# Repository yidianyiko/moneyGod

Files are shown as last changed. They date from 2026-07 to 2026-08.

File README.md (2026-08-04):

# 赛博财神庙 (MoneyGod)

AdventureX 2026 黑客松项目 — 一台桌面"财神"装置：摇签 → 抽档 → LLM 生成签诗 + 解签 → TTS 语音播报 → 热敏打印签条。

核心硬件基于 Tuya T5AI 开发板 + 热敏打印机 + 磁悬浮展示 + 摇签遥控器，外壳为 3D 打印件。后端 Python 服务提供签文生成、TTS 合成等 API。

> 详细架构与开发指南见 [`CLAUDE.md`](CLAUDE.md)。

## 成品展示

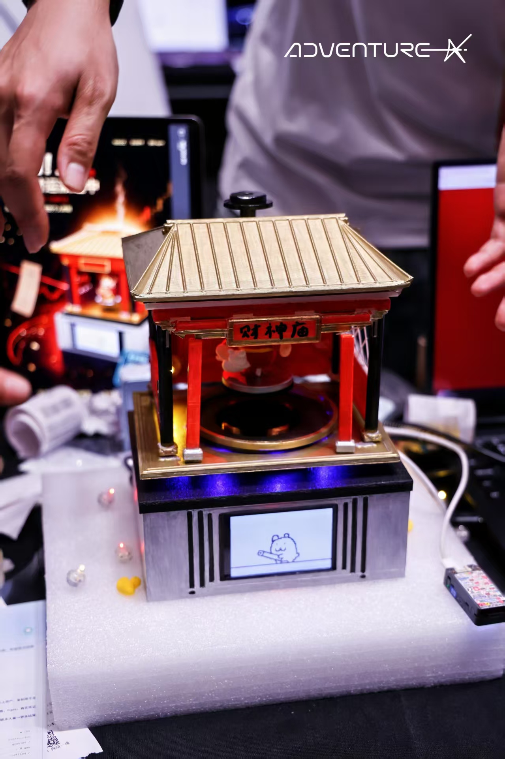
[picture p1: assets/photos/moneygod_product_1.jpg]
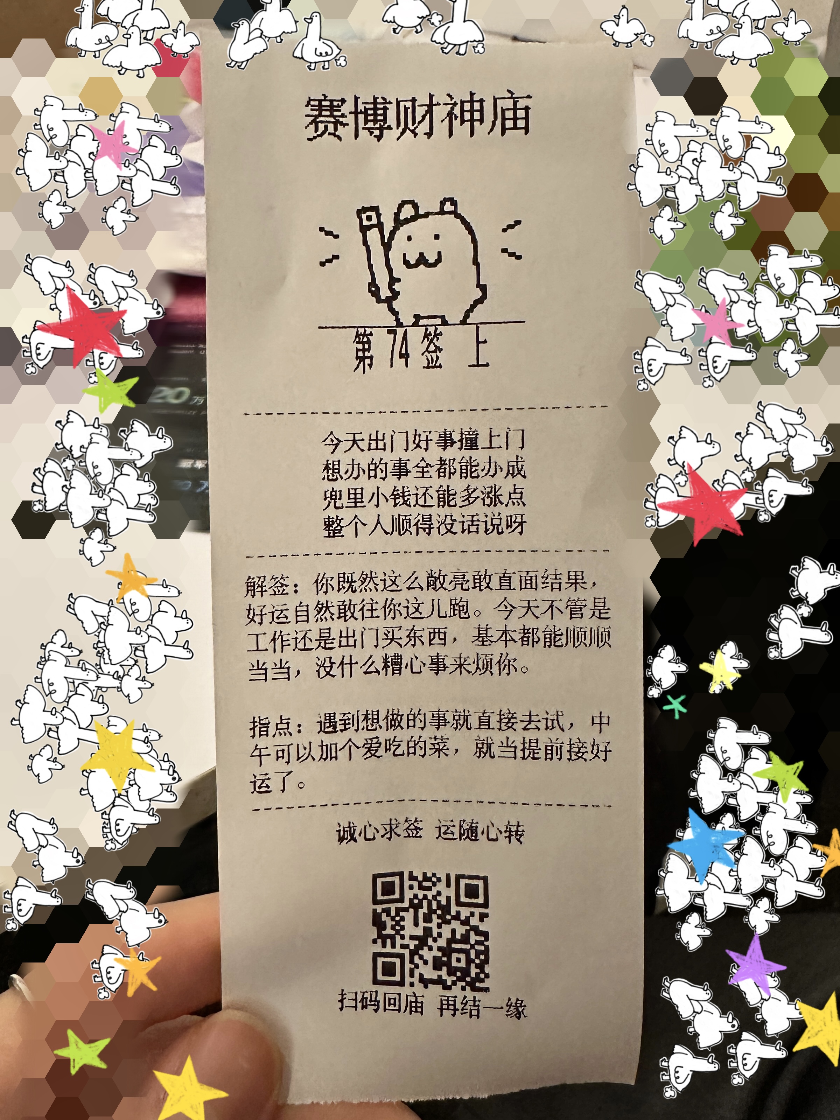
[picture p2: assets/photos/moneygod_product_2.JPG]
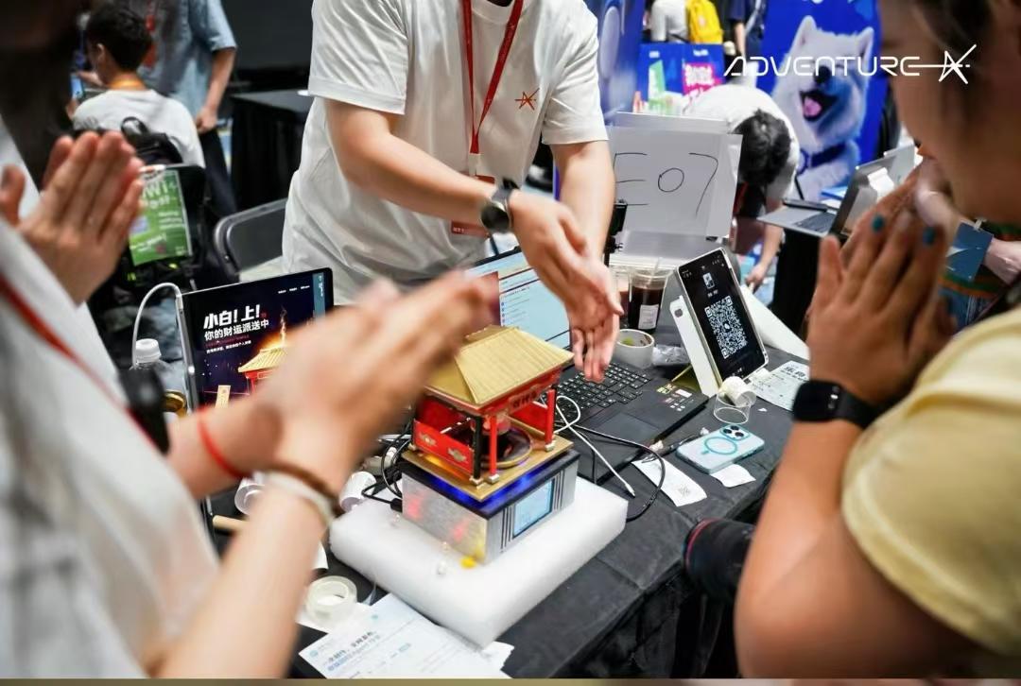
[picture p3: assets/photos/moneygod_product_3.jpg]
<table> <tr> <td align="center" valign="top" width="50%">  </td> <td align="center" valign="top" width="50%">  </td> </tr> </table>   

---

## 硬件清单 (BOM)

> 📝 搜索建议：可直接在淘宝/电商平台搜索以下商品名称。

> 💰 完整成本明细（含各模块单独成本）见 [成本.md](成本.md)。

### 核心电子模块

| # | 名称 | 型号 / 规格 | 用途 |
|---|---|---|---|
| 1 | 雾化加湿器模块 | 适用 Arduino / ESP32，含连接线 | 财神烟雾效果 |
| 2 | 磁悬浮机芯 | 磁悬浮裸机机芯，悬浮展示架，负载 500–600 g (4B) | 财神悬浮展示 |
| 3 | 嵌入式热敏打印模块 | **EM5820H**，白色新版，5–9 V，USB 供电 | 签文打印 |

### 主控板

本项目使用涂鸦 **T5AI 开发板**，但也可使用其他支持相应外设的开发板（感谢清闲提供的香橙派 OrangePi 3B 对本项目完整运行的帮助）。

| 名称 | 说明 |
|---|---|
| **Tuya T5AI 开发板** | 主控，运行 `t5-dev/TuyaOpen/apps/cyber_fortune/` 固件。屏幕、TTS、BLE 摇签、网络抽签均在此板。 |
| **StickS3** | 摇签遥控器，PlatformIO 固件在 `stick-dev/`。通过 BLE 与 T5AI 通信。 |

### 3D 打印外壳

共 13 个 STL 零件（庙顶、庙身、底座、屏幕支架、热敏打印机支架、磁悬浮环等），详见 [`hardware/3d-models/README.md`](hardware/3d-models/README.md)。

### 硬件文档

- 屏幕 / 摄像头模块尺寸与原理图：[`t5-dev/hardware/`](t5-dev/hardware/)
- 热敏打印机 EM5820H 规格书与开发笔记：[`t5-dev/hardware/printer/EM5820H-USB打印开发笔记.md`](t5-dev/hardware/printer/EM5820H-USB打印开发笔记.md)
- 3D 打印外壳零件清单：[`hardware/3d-models/README.md`](hardware/3d-models/README.md)

---

## 项目结构

```
core-engine/          Python 后端 — 唯一运行的服务
t5-dev/               T5AI 板固件 + 构建/烧录脚本
  └─ TuyaOpen/        TuyaOpen SDK (git subtree)
stick-dev/            StickS3 摇签遥控器固件 (PlatformIO)
hardware/3d-models/   外壳 STL (13 件)
assets/               像素美术素材
scene_change_gifs/    动画
赛博财神庙_原创签谱.json   原始签诗数据
```

## 快速开始

```bash
# 后端
cd core-engine
cp .env.example .env          # 填入 ARK_API_KEY / VOLC_TTS_APPID / VOLC_TTS_TOKEN
.venv/bin/python quickstart.py   # 验证 LLM 连通
.venv/bin/python serve.py        # 启动签文 API (0.0.0.0:8000)

# 固件 (从仓库根目录)
bash t5-dev/cf_build.sh          # 增量编译
bash t5-dev/cf_flash.sh          # 烧录
bash t5-dev/cf_monitor.sh        # 串口监视
```

## License

MIT

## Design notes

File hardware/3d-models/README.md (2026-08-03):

# 赛博财神庙 — 外壳 3D 模型（最终确定版）

整台设备的外壳打印件：庙顶、庙身、底座、以及固定屏幕 / 热敏打印机 / 磁悬浮环的支架。
共 13 个零件，全部是 **binary STL**，单位 **毫米**，直接丢进切片软件即可。

## 下载

**网页上单个下载** — 在 GitHub 点开任意 `.stl` 会直接渲染 3D 预览，右上角 `Download` 即可：

<https://github.com/yidianyiko/moneyGod/tree/master/hardware/3d-models>

**命令行一次拿全部** — 仓库里带了 TuyaOpen SDK，很大，用稀疏检出只拉这个目录：

```bash
git clone --filter=blob:none --no-checkout https://github.com/yidianyiko/moneyGod.git
cd moneyGod
git sparse-checkout set hardware/3d-models
git checkout master
# 模型在 hardware/3d-models/
```

## 零件清单

尺寸为模型包围盒 `X × Y × Z`（mm），已按摆放姿态给出。

| 文件 | 零件 | 尺寸 (mm) | 三角面 |
|---|---|---|---|
| `01_roof.stl` | 庙顶（带瓦楞造型，面数最高） | 180 × 140 × 35 | 151,264 |
| `02_roof_liner.stl` | 庙顶内衬 | 164 × 124 × 6.2 | 2,156 |
| `0301.stl` | 03 组件 · 薄底板（与内衬同 XY） | 164 × 124 × 3.0 | 208 |
| `0302.stl` | 03 组件 · 外檐板 | 216 × 150 × 6.0 | 1,692 |
| `0303.stl` | 03 组件 · 庙身主体（最高件） | 154 × 120 × 105 | 35,394 |
| `04.stl` | 04 层板 | 168.1 × 128.4 × 5.9 | 2,702 |
| `08_top_platform.stl` | 顶部平台 | 174 × 134 × 4.9 | 49,320 |
| `09_maglev_ring.stl` | 磁悬浮环 | 108 × 108 × 5.0 | 768 |
| `11_base_shell.stl` | 底座外壳 | 180 × 140 × 75 | 5,128 |
| `13_display_bracket.stl` | 屏幕支架（立式薄片） | 101 × 3 × 70 | 208 |
| `16_printer_bracket.stl` | 热敏打印机支架（EM5820H） | 109 × 54.5 × 1.2 | 32 |
| `18_rear_cover.stl` | 后盖（立式薄片） | 166 × 3 × 61 | 332 |
| `19_bottom_plate.stl` | 底板 | 174 × 134 × 3.0 | 96 |

关于命名，两点需要知道：

- 编号有跳号（缺 05–07、10、12、14、15、17）。这些是设计过程中的内部编号，最终装配不需要，不是漏传。
- `0301/0302/0303/04` 出自 Shapr3D，其余出自另一套建模流程（STL 头为空）。名字保持发来时的原样，没有重命名，避免和硬件同学的图纸对不上。上表的"零件"一列是按尺寸和装配关系推断的，**装配前请以实际图纸为准**。

## 打印建议

- **最大底面 180 × 140 mm**（`01_roof` / `11_base_shell`），220 mm 及以上热床都放得下（Ender-3、Bambu A1/P1S 均可）。
- **最高件 105 mm**（`0303`）。
- `01_roof` 有 15 万面，切片会慢一点，属正常。
- `13_display_bracket`、`18_rear_cover`、`16_printer_bracket` 是 1.2–3 mm 的薄片，**平铺打印**，别立着打。
- 层高 0.2 mm、PLA、支撑视庙顶挑檐角度而定即可，没有特殊工艺要求。

## 装配相关的其它资料

- 屏幕 / 摄像头模块尺寸与原理图：[`t5-dev/hardware/`](../../t5-dev/hardware/)
- 热敏打印机 EM5820H 规格书：[`t5-dev/hardware/printer/`](../../t5-dev/hardware/printer/)

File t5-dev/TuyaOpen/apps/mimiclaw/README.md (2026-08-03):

## TuyaOpen With MimiClaw Running on T5AI

This project runs the **open‑source MimiClaw project**, an OpenClaw‑style local‑first AI assistant, on the **Tuya T5AI** development board and optional **Linux runtime**.  
Plug in power, connect Wi‑Fi, and your T5AI board becomes a 24/7 AI butler that talks to you via Feishu / Telegram / Discord, calls mainstream LLMs (DeepSeek, Claude, GPT, etc.), remembers you in local text files, and can directly operate rich TuyaOpen hardware peripherals.

TuyaOpen provides drivers, display, peripherals, and connectivity layers, greatly expanding what MimiClaw can do on real products: AI lamps, pet robots, toys, dashboards, and more — all powered by an embedded agent that lives entirely on your device.

**Disclaimer / trademarks**: This is an independent, unofficial TuyaOpen‑based port that runs the open‑source MimiClaw firmware on Tuya hardware. It is not an official product of Tuya, the MimiClaw maintainers, or any model / platform providers mentioned here. “MimiClaw”, “OpenClaw”, “Telegram”, “Discord”, “Feishu” and all model/provider names are trademarks or service marks of their respective owners.

### What you get

- **Local‑first AI assistant** running on Tuya T5AI or Linux
- **Multiple LLM providers**: DeepSeek, Qwen, Claude, GPT, MiniMax, and other OpenAI/Anthropic‑compatible endpoints
- **Multiple chat channels**: Telegram / Discord / Feishu (configurable)
- **Persistent memory** stored as plain text on flash
- **Cron‑style scheduler & heartbeat loop** so the AI can wake itself up and act
- **Direct hardware control** via TuyaOpen drivers, sensors, and GPIOs

---

## What’s different from the upstream MimiClaw project

Upstream repository: [`memovai/mimiclaw`](https://github.com/memovai/mimiclaw)

This TuyaOpen port is **based on** the upstream MimiClaw project and keeps the core ideas (embedded agent loop, tools, cron, heartbeat, local memory), but makes several changes:

- **Target hardware**
  - **Tuya T5AI board** as a first‑class target, with TuyaOpen’s SDK, display, and peripherals
  - **Linux runtime** support for development, debugging, and running the agent directly on a host
- **Chat channels**
  - Adds first‑class **Feishu** support, in addition to **Telegram** and **Discord**
  - Unified CLI to switch the active channel at runtime
- **Model configuration**
  - Supports **OpenAI**, **Anthropic**, and **MiniMax** providers, plus **compatible base URLs**
  - CLI and config‑file driven model/provider selection
- **TuyaOpen integration**
  - Uses TuyaOpen’s rich **drivers, sensors, and displays**, enabling the AI to read sensors, drive GPIOs, and control more complex hardware devices
  - Fits into the TuyaOpen examples/app structure under `apps/tuya_mimiclaw`

Please refer to the upstream README for detailed architecture notes of MimiClaw itself; this document focuses on the TuyaOpen‑specific integration and usage.

---

## Quick migration & configuration guide (TuyaOpen MimiClaw port)

These steps assume you have already built and flashed the firmware (or are running the Linux runtime).  
Connect to the **serial console at 115200 baud**, open the programming port, and you will see the CLI.

### 1. Discover CLI commands

After opening the serial console (115200), type:

```text
help
```

This prints the list of supported CLI commands for this port.

### 2. Configure model provider & API

You can choose `openai`, `anthropic`, or `minimax` as the provider. The project also supports **OpenAI/Anthropic‑compatible base URLs**.

Typical steps:

1. Select provider (for example, OpenAI, Anthropic, or MiniMax):
   - `set_model_provider openai`
   - or `set_model_provider anthropic`
   - or `set_model_provider minimax`
2. Set API key:
   - `set_api_key sk-xxxx...`
3. (Optional) Use a compatible API base URL:
   - `set_api_url https://your-compatible-endpoint.example.com`
4. Set model name:
   - `set_model gpt-4o` (or any supported model by your provider)
   - For MiniMax: `set_model MiniMax-M2.7` or `set_model MiniMax-M2.5-highspeed` (204K context)

If you provide a compatible URL, make sure both **API_KEY** and **API_URL** are set, otherwise calls will fail.

### 3. Connect to Wi‑Fi

Use the CLI to configure your router SSID and password:

```text
set_wifi <ssid> <password>
restart
```

After `restart`, the device will reconnect using the new Wi‑Fi settings.

### 4. Choose your chat channel (Telegram / Discord / Feishu)

You can run MimiClaw through different social channels. Currently supported:

- `telegram`
- `discord`
- `feishu`

Switch the active channel:

```text
set_channel_mode telegram
```

or

```text
set_channel_mode feishu
```

or

```text
set_channel_mode discord
```

Then, according to the selected channel, configure the required credentials (token / appid / secret, etc.) via the CLI. After configuration, reboot:

```text
restart
```

### 5. Configure via `mimi_secrets.h` (optional)

Instead of entering everything over serial, you can pre‑configure secrets at build time:

1. Copy the example file:

   ```bash
   cp apps/tuya_mimiclaw/mimi_secrets.h.example apps/tuya_mimiclaw/mimi_secrets.h
   ```

2. Edit `mimi_secrets.h` and fill in Wi‑Fi credentials, API keys, model provider, chat channel, and any optional settings.
3. Rebuild and flash the firmware so the new defaults are baked in.

### 6. Configuration priority rules

- **CLI settings have the highest priority.**  
  Any parameter set via the serial CLI overrides build‑time settings.
- If a value is **not set in the CLI**, the firmware falls back to **`mimi_secrets.h`**.
- If a required parameter is missing **both** in CLI and in `mimi_secrets.h`, the program will error or refuse to start the corresponding feature.

This makes it easy to ship sensible defaults in firmware while still allowing flexible per‑device overrides in the field.

---

## Supported chipsets / runtimes

| Name | Support Status | Notes |
| --- | --- | --- |
| Tuya T5AI board | Supported | Main embedded target; uses TuyaOpen SDK, display, and hardware stack. |
| Linux runtime | Supported | Run the same agent loop directly on a Linux host for dev and testing. |

---

## Acknowledgements

This project is **heavily inspired by and derived from** the upstream work in [`memovai/mimiclaw`](https://github.com/memovai/mimiclaw), which demonstrates how to run an OpenClaw‑style AI assistant on an ESP32‑S3 with:

- Pure C firmware, no Linux or heavy runtime
- Local‑first memory and on‑device text files (`SOUL.md`, `USER.md`, `MEMORY.md`, etc.)
- Tool calling, cron scheduler, and heartbeat‑driven autonomous tasks

This TuyaOpen‑based MimiClaw port keeps these core ideas and adapts them to the **TuyaOpen** ecosystem, focusing on:

- T5AI hardware, displays, and peripherals
- Integration with TuyaOpen’s AI/IoT workflows
- Expanded channel and model options for real products

Original MimiClaw is licensed under the **MIT License**; please refer to the upstream repository for full license details and ongoing development. We are deeply grateful to the MimiClaw authors and community for making this possible.

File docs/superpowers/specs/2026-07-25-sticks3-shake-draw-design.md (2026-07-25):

# StickS3 摇签遥控器设计（BLE 广播联动 · Stick 侧）

日期：2026-07-25
状态：已确认（用户批准方案 A：无连接 BLE 广播）
范围修订：本 spec 只覆盖 **BLE 广播协议 + StickS3 固件**。T5AI 侧集成因 cyber-fortune-v2
（`2026-07-25-cyber-fortune-v2-design.md`）正在实施中，拆分至独立 spec
`2026-07-25-t5-ble-remote-design.md`，v2 落地后单独排期实现。Stick 固件与 T5 代码零交集，可并行开发。

## 背景与目标

赛博财神庙当前由 T5AI-Board（TuyaOpen + LVGL，`t5-dev/TuyaOpen/apps/cyber_fortune`）承担触屏求签 UI 与 USB 打印。
新增硬件 M5Stack **StickS3**（SKU:K150）作为手持"签筒"：用户摇晃 StickS3 即触发大屏求签，
等价于点击屏幕上的「求签」按钮。

- 产品页：https://docs.m5stack.com/zh_CN/core/StickS3
- 商店页：https://shop.m5stack.com/products/m5sticks3-esp32s3-mini-iot-dev-kit

### 关键硬件事实

| 项 | StickS3 | T5AI-Board |
|---|---|---|
| 主控 | ESP32-S3-PICO-1-N8R8（8MB Flash / 8MB PSRAM） | Tuya T5（BK7258 系） |
| 无线 | 2.4G WiFi + **BLE 5.0（无经典蓝牙）** | WiFi + BLE（`tal_bluetooth`，有 `ble_central` 例程） |
| 传感器 | **BMI270 六轴 IMU**（I2C 0x68，摇动检测核心） | — |
| 交互 | 1.14" ST7789P3 135x240 LCD、扬声器（ES8311+AW8737）、双按键 | 3.5" ILI9488 480x320 触屏 |
| 供电 | 250mAh 电池 + USB Type-C | USB |
| 刷机 | Type-C 原生 USB CDC，PlatformIO 自动进 boot；手动方式：连 USB 长按侧边复位键至绿 LED 闪 | CH343（无自动复位） |

## 需求决策（已与用户确认）

1. **触发方式：两者并存** —— 触屏「求签」按钮保留，摇 StickS3 同样触发；Stick 离线不影响触屏流程。
2. **摇签时机：全局响应** —— 待机页摇动=求签；结果页摇动=等价「再求一签」并立即重摇；求签动画中忽略。
3. **技术栈**（用户委托决定）：StickS3 侧 PlatformIO + Arduino + M5Unified；连接采用**方案 A：无连接 BLE 广播**。

### 备选方案（已否决）

- 方案 B（GATT 长连接）：可双向通信但需断线重连状态机，展会 2.4G 干扰下稳定性差，工程量 2~3 倍。协议中预留事件类型字段，未来可升级。
- 方案 C（WiFi 局域网/后端中转）：依赖场地 WiFi 与配网，链路环节最多。

## 1. 通信协议

StickS3 检测到摇动后，将事件写入 BLE 广播包的 **Manufacturer Specific Data（AD Type 0xFF）**：

```
偏移  字段            值/说明
0-1   厂商ID          0xFF 0xFF（测试保留值）
2-3   魔数            0x43 0x46（"CF"，过滤无关广播）
4     协议版本        0x01
5     事件类型        0x01 = 摇签（0x02+ 预留）
6     事件序号        每次摇签 +1，uint8 滚动，用于去重
7     电量百分比      0-100，T5 侧暂不消费，预留
```

- 触发后以 **50ms 间隔连发 1.5 秒**广播，随后停止（连发抗丢包）。
- T5AI 侧记录上一事件序号，**序号变化才触发**，天然去重。
- 无配对、无连接状态：Stick 重启/换电/离场返回均零恢复成本。

## 2. StickS3 固件（新增）

目录：`stick-dev/cf_stick/`（与 `t5-dev` 平级），PlatformIO 工程，`platformio.ini`
采用官方推荐配置（`espressif32@6.12.0`、`esp32-s3-devkitc-1`、`qio_opi`、
`ARDUINO_USB_CDC_ON_BOOT=1`），依赖 M5Unified + M5PM1。

- **摇动检测**：BMI270 加速度模长阈值（约 2g）+ 短窗口内多峰判定；触发后 **2 秒冷却**防连触。
- **本地仪式感**（不依赖回传，已确认：GIF 动画 + 音效，**不做震动**——StickS3 无内置震动马达）：
  - 屏幕旋转为横屏 **240×135**，与现有素材同比例（3:2）；
  - 待机循环播放 `scene_change_gifs/thinking.gif`（480×320 → 离线缩放到 240×135、降帧降色减体积）；
  - 摇动触发：播放摇签音效（WAV，M5Unified Speaker API）+ 播一遍 `getting_lottery.gif`，结束回待机；
  - GIF 用 `AnimatedGIF` 解码库 + M5GFX 渲染，素材以 C 数组形式编进固件（8MB Flash 富余）；
  - 屏幕角落叠加电量百分比；
  - ⚠️ 电池供电时音量上限 75%（官方警告：过大功率会触发重启）。
- **BLE**：ESP32 Arduino BLEAdvertising API 动态设置厂商数据、启停广播。
- **供电**：展会默认 USB/充电宝供电，250mAh 电池仅作短时移动缓冲。
- 配套脚本：`cf_stick_build.sh` / `cf_stick_flash.sh`（含 `pio device monitor` 提示），与现有 `cf_*` 工作流一致。

## 3. T5AI 侧改动（已拆分，另行实施）

详见 `2026-07-25-t5-ble-remote-design.md`。本 spec 的第 1 节协议即双方共享契约，
T5 侧实现时以此为准，协议字段不得单方变更。

## 4. 容错与边界

| 场景 | 行为 |
|---|---|
| Stick 没电/丢失/离场 | 触屏求签照常可用 |
| 广播包重复接收 | 事件序号去重，只触发一次 |
| 连续疯狂摇动 | Stick 侧 2s 冷却 + T5 侧 `s_drawing` 期间忽略 |
| T5 BLE 初始化失败 | 打日志降级，主流程不受影响 |
| 展会 2.4G 干扰 | 1.5s × 50ms 广播连发冗余抗丢包 |

## 5. 测试计划（本期只测 Stick 侧）

1. **摇动检测**：串口日志验证灵敏度与 2s 冷却；冷却周期内连摇 10 次仅触发 1 次。
2. **广播协议**：手机 nRF Connect 抓广播包，核对厂商数据各字段与序号递增；1.5s 后广播确实停止。
3. **本地反馈**：待机 GIF 循环流畅；摇动后音效 + getting_lottery 动画播放完整并回待机；电量显示正确。
4. **供电**：电池供电下音量 75% 播放不重启；拔电重启后无需任何操作恢复工作。

端到端联动测试（摇 Stick → 大屏出签 → 打印出票）归入 T5 侧 spec，待其实现后进行。

## 假设

- StickS3 到手后 BMI270 阈值需实测微调（阈值/峰数作为固件顶部常量便于调参）。
- 展会现场只有一支 Stick 与一块 T5AI 板，协议暂不做设备配对绑定；如未来多套并存，可在厂商数据中追加设备 ID 字段过滤。
- GIF 素材缩放到 240×135 并降帧后单个体积可控制在数百 KB 内，8MB Flash 足够容纳 2 个动画 + 音效 WAV（实施时如超限改用 LittleFS 分区存储）。
- 震动反馈不做：StickS3 无内置震动马达；Grove 口（G9/G10 + 5V，需开 EXT_5V 输出）保留为未来外接震动马达模块的升级路径。

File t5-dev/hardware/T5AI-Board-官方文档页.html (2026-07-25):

跳到主要内容

本页总览

# T5AI-Board 开发套件

T5AI-Board 是一款基于涂鸦 T5-E1-IPEX Wi-Fi 与蓝牙组合模组的语音与屏幕交互开发板。板载 2 个麦克风和 1 个扬声器以支持语音交互，并完整引出模组引脚，便于堆叠 LCD 与摄像头模块或自行连接外设。可用它以标准 TuyaOpen 流程快速开发 AIoT 语音与显示应用。

T5AI-Board 开发板正面图

T5AI-Board 开发板正面图

## 软件编译配置

板级配置文件定义了外设驱动、引脚映射、BSP 包以及第三方库等核心功能组件的配置参数。通过使用开发板预配置的板级配置文件，可以显著降低硬件适配和驱动开发的工作量，提高开发效率。

:::tip 想要开发新的外设？ Config 配置特点：

- 开发者如需新增外设，可直接在应用层编写驱动。 BSP 驱动主要用于板卡内部固化的外围器件。
- 不同应用的外设需求可能存在配置差异，需要根据具体需求调整 Config 文件。
- 不同应用需求可能需要配置不同的第三方库参数。
- 建议 以初始配置文件作为 板级基础模板，在此基础上进行二次开发和功能扩展。 :::

如何使能 Config？请参阅 CLI - tos.py 开发工具 - 配置选择。

编译标志 | TUYA_T5AI_BOARD_LCD_3.5.config | T5AI-Board + 3.5 寸屏幕 BSP 板卡配置 - 配置文件 (https://github.com/tuya/TuyaOpen/blob/master/apps/tuya.ai/your_chat_bot/config/TUYA_T5AI_BOARD_LCD_3.5.config)
BSP 驱动源码 | T5AI-Board BSP 驱动源码 (https://github.com/tuya/TuyaOpen/tree/master/boards/T5AI/TUYA_T5AI_BOARD)

## 硬件概述

T5AI-Board 基于 T5-E1-IPEX 模组，该模组是涂鸦智能开发的嵌入式 Wi-Fi 和蓝牙组合模组。开发板配备 2 个麦克风和 1 个扬声器，支持语音识别与播放，实现语音交互功能。

通过开发板上的 I/O 连接器，您可以堆叠 LCD 显示模块以实现触摸屏与摄像头采集功能。您也可以自行设计 LCD 屏幕，支持 I2C、SPI、8080 和 RGB 等多种接口。

## 开发套件亮点

- 涂鸦 T5 MCU 模块（Wi-Fi 2.4 GHz + 蓝牙 LE 5.4）
- 8 MB Flash
- 16 MB RAM
- 串行固件下载和调试日志
- 2 通道麦克风
- 1 通道扬声器
- TF 卡槽
- 模块完整引脚引出
- 板载 2.4 GHz Wi-Fi 天线
- USB 主机接口
- USB 供电
- （可选堆叠模块）RGB565 显示 + DVP 摄像头支持

## 详细规格

特性 | 规格
板载模块 | T5-E1-IPEX
CPU | ARMv8-M Star (M33F) @480MHz
缓存 | 16KB ITCM 和 16KB DTCM
闪存 | 8 MB SiP 闪存
RAM | 16 MB SiP PSRAM
SRAM | 640 KB 共享 SRAM
音频 ADC | 2 通道 16 位 48KHz
音频 DAC | 1 通道 16 位 48KHz
均衡器 | 4 段数字均衡器
摄像头 | DVP 接口
显示 | RGB 和 8080 接口
扩展 | TF 卡支持
GPIO | 56 个 GPIO
接口 | 2x SPI、2x QSPI、3x UART、2x I2C、1x SDIO、1x CAN、12x PWM、3x I2S
标准 | 符合 IEEE 802.11b/g/n/ax
蓝牙 | 蓝牙 LE 5.4
USB type-C | 输入：5V@1A，固件下载和调试

## 引脚定义

T5AI-Board 通过其扩展接头提供全面的引脚选项。以下是可用引脚及其功能的详细说明：

T5AI-Board 引脚图

T5AI-Board 引脚图

### 下载高清引脚图



## LCD 屏幕与摄像头模块

T5AI-Board 支持可选的 LCD 屏幕和摄像头模块，可堆叠在主板上。

### 显示规格

- 3.5" TFT 显示屏，320×480 RGB 分辨率
- TFT 显示驱动：ILI9488
- 触摸面板驱动：GT1151QM

### 摄像头规格

- 图像传感器：GC2145
- 分辨率：2 MP（1616 x 1232 像素）
- I2C 通信地址：0x78 和 0x79
- 查看摄像头数据手册 (https://e2e.ti.com/cfs-file/__key/communityserver-discussions-components-files/968/GC2145-CSP-DataSheet-release-V1.0_5F00_20131201.pdf)

### 引脚配置

下图显示了 LCD 屏幕和摄像头模块使用的引脚分配：

堆叠的 LCD 与摄像头模块引脚分配

堆叠的 LCD 与摄像头模块引脚分配

:::info 重要引脚注意事项

- 摄像头和触摸面板共享一个公共 I2C 接口。
- TF 卡引脚 DATA3 和 DATA2 与模块的 UART 端口共享，用于固件更新。 :::

## 下载资源

### T5AI-Board 开发板

- T5AI-Board 原理图 (https://images.tuyacn.com/content-platform/hestia/174243908480e34e64d08.pdf)：T5AI-Board 完整电路图。
- T5AI-Board 引脚图：详细的引脚映射和接口布局。
- LCD 和摄像头模块原理图 (https://images.tuyacn.com/content-platform/hestia/17387200670bcae1561bf.pdf)：显示和摄像头模块板的电路图。
- T5AI-Board 3D 结构文件(LCD+Base-Board)（STEP）：提供 T5AI-Board 开发板的 3D 结构模型，便于结构设计与集成。

### T5 MCU 数据手册

- T5-E1-IPEX 模块数据手册 (https://developer.tuya.com/en/docs/iot/T5-E1-IPEX-Module-Datasheet?id=Kdskxvxe835tq)：T5-E1-IPEX 模块的技术规格和引脚定义。
- T5 MCU 芯片技术数据手册 (https://images.tuyaeu.com/content-platform/hestia/1731549161e5fd8879de6.pdf)：T5 系列的综合技术规格和参考文档。

### USB 转串口驱动安装

T5AI-Board 使用板载 CH343 USB 转串口芯片进行固件烧录和调试。请下载适合您操作系统的驱动程序：

- Windows 驱动 (https://www.wch-ic.com/downloads/CH343SER_ZIP.html)
- Linux 驱动 (https://github.com/WCHSoftGroup/ch343ser_linux)
- macOS 驱动 (https://github.com/WCHSoftGroup/ch34xser_macos)

## 相关技术文档/Demo

- T5AI-Board 入门指南 - (环境搭建 + 烧录 Demo）
- T5AI-Board Demo 聊天机器人
- T5AI-Board Demo IoT 智能插座/灯
- T5AI-Board Demo Wi-Fi/BT 和其他外设

编辑此页 (https://github.com/Tuya-Community/TuyaOpen.io/edit/master/i18n/zh/docusaurus-plugin-content-docs/current/hardware/tuya-t5/t5-ai-board/overview-t5-ai-board.md)

- 软件编译配置
- 硬件概述
- 开发套件亮点
- 详细规格
- 引脚定义
  - 下载高清引脚图
- LCD 屏幕与摄像头模块
  - 显示规格
  - 摄像头规格
  - 引脚配置
- 下载资源
  - T5AI-Board 开发板
  - T5 MCU 数据手册
  - USB 转串口驱动安装
- 相关技术文档/Demo

Products

- TuyaOpen IDE
- TuyaOpen SDK (https://github.com/tuya/TuyaOpen)
- TuyaOpen on Arduino (https://github.com/tuya/arduino-TuyaOpen)
- TuyaOpenClaw 🦞

文档

- 快速试用
- About TuyaOpen
- 硬件支持清单
- Tuya T5AI 开发套件
- License Key

工具

- TyuTools GUI/CLI
- Web Serial 工具

社区

- 论坛 (https://forum-tuyaopen.discourse.group/)
- FAQ
- 博客
- Discord (https://discord.com/invite/yPPShSTttG)
- X (https://x.com/tuyasmart)
- YouTube (https://www.youtube.com/@tuya2023)
- LinkedIn (https://www.linkedin.com/company/tuya-smart)

更多

- GitHub (https://github.com/tuya/TuyaOpen)
- Gitee (Mirror) (https://gitee.com/tuya-open/TuyaOpen)
- Projects

法律

- 服务条款 (https://auth.tuya.com/policies/service)
- 法律声明 (https://auth.tuya.com/policies/legal)
- 涂鸦隐私政策 (https://auth.tuya.com/policies/privacy)
- Tuya 加州隐私声明 (https://auth.tuya.com/policies/CAprivacynotice)

版权所有 © TuyaOpen Authors 2025 | Documentation Distributed under Apache License Version 2.0 (https://www.apache.org/licenses/LICENSE-2.0)

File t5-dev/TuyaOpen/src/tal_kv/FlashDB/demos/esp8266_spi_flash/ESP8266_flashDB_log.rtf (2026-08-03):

ets Jan 8 2013,rst cause:2, boot mode:(3,7)

load 0x40100000, len 7196, room 16
tail 12
chksum 0xc1
ho 0 tail 12 room 4
load 0x3ffe8408, len 24, room 12
tail 12
chksum 0x48
ho 0 tail 12 room 4
load 0x3ffe8420, len 3548, room 12
tail 0
chksum 0x18
I (49) boot: ESP-IDF v3.2-252-g73bf28b-dirty 2nd stage bootloader
I (49) boot: compile time 10:40:57
I (50) qio_mode: Enabling default flash chip QIO
I (58) boot: SPI Speed : 40MHz
I (64) boot: SPI Mode : QIO
I (70) boot: SPI Flash Size : 2MB
I (76) boot: Partition Table:
I (82) boot: ## Label Usage Type ST Offset Length
I (93) boot: 0 nvs WiFi data 01 02 00009000 00006000
I (105) boot: 1 phy_init RF data 01 01 0000f000 00001000
I (116) boot: 2 factory factory app 00 00 00010000 000f0000
I (128) boot: End of partition table
I (135) esp_image: segment 0: paddr=0x00010010 vaddr=0x40210010 size=0x26ee0 (159456) map
I (201) esp_image: segment 1: paddr=0x00036ef8 vaddr=0x40236ef0 size=0x05e00 ( 24064) map
I (210) esp_image: segment 2: paddr=0x0003cd00 vaddr=0x3ffe8000 size=0x005f4 ( 1524) load
I (212) esp_image: segment 3: paddr=0x0003d2fc vaddr=0x40100000 size=0x00a30 ( 2608) load
I (226) esp_image: segment 4: paddr=0x0003dd34 vaddr=0x40100a30 size=0x05328 ( 21288) load
I (246) boot: Loaded app from partition at offset 0x10000
I (268) system_api: Base MAC address is not set, read default base MAC address from EFUSE
I (273) system_api: Base MAC address is not set, read default base MAC address from EFUSE
phy_version: 1155.0, 6cb3053, Nov 11 2019, 17:31:08, RTOS new
I (328) phy_init: phy ver: 1155_0
I (331) reset_reason: RTC reset 2 wakeup 0 store 0, reason is 2
Hello world!
This is ESP8266 chip with 1 CPU cores, WiFi, silicon revision 1, 2MB external flash
[I/FAL] Flash Abstraction Layer (V0.5.0) initialize success.
[FlashDB][kv][env] (/home/syj0925/esp/esp8266_spi_flash/components/FlashDB/src/fdb_kvdb.c:1599) KVDB in partition fdb_kvdb1, size is zu bytes.
[FlashDB] FlashDB V1.0.0 beta is initialize success.
[FlashDB] You can get the latest version on https://github.com/armink/FlashDB .
[FlashDB][sample][kvdb][basic] get the 'boot_count' value is 22
[FlashDB][sample][kvdb][basic] set the 'boot_count' value to 23
[FlashDB][sample][kvdb][string] create the 'temp' string KV, value is: 36C
[FlashDB][sample][kvdb][string] get the 'temp' value is: 36C
[FlashDB][sample][kvdb][string] set 'temp' value to 38C
[FlashDB][sample][kvdb][string] delete the 'temp' finish
[FlashDB][sample][kvdb][blob] create the 'temp' blob KV, value is: 36
[FlashDB][sample][kvdb][blob] get the 'temp' value is: 36
[FlashDB][sample][kvdb][blob] set 'temp' value to 38
[FlashDB][sample][kvdb][blob] delete the 'temp' finish
[FlashDB][tsl][log] (/home/syj0925/esp/esp8266_spi_flash/components/FlashDB/src/fdb_tsdb.c:759) TSDB (log) oldest sectors is 0x00000000, current using sector is 0x00000000.
[FlashDB][sample][tsdb] append the new status.temp (36) and status.humi (85)
[FlashDB][sample][tsdb] append the new status.temp (38) and status.humi (90)
[FlashDB][sample][tsdb] queried a TSL: time: 1, temp: 36, humi: 85
[FlashDB][sample][tsdb] queried a TSL: time: 2, temp: 38, humi: 90
[FlashDB][sample][tsdb] queried a TSL: time: 3, temp: 36, humi: 85
[FlashDB][sample][tsdb] queried a TSL: time: 4, temp: 38, humi: 90
[FlashDB][sample][tsdb] queried a TSL: time: 5, temp: 36, humi: 85
[FlashDB][sample][tsdb] queried a TSL: time: 6, temp: 38, humi: 90
[FlashDB][sample][tsdb] queried a TSL: time: 7, temp: 36, humi: 85
[FlashDB][sample][tsdb] queried a TSL: time: 8, temp: 38, humi: 90
[FlashDB][sample][tsdb] queried a TSL: time: 9, temp: 36, humi: 85
[FlashDB][sample][tsdb] queried a TSL: time: 10, temp: 38, humi: 90
[FlashDB][sample][tsdb] queried a TSL: time: 11, temp: 36, humi: 85
[FlashDB][sample][tsdb] queried a TSL: time: 12, temp: 38, humi: 90
[FlashDB][sample][tsdb] queried a TSL: time: 13, temp: 36, humi: 85
[FlashDB][sample][tsdb] queried a TSL: time: 14, temp: 38, humi: 90
[FlashDB][sample][tsdb] queried a TSL: time: 15, temp: 36, humi: 85
[FlashDB][sample][tsdb] queried a TSL: time: 16, temp: 38, humi: 90
[FlashDB][sample][tsdb] queried a TSL: time: 17, temp: 36, humi: 85
[FlashDB][sample][tsdb] queried a TSL: time: 18, temp: 38, humi: 90
[FlashDB][sample][tsdb] queried a TSL: time: 19, temp: 36, humi: 85
[FlashDB][sample][tsdb] queried a TSL: time: 20, temp: 38, humi: 90
[FlashDB][sample][tsdb] queried a TSL: time: 21, temp: 36, humi: 85
[FlashDB][sample][tsdb] queried a TSL: time: 22, temp: 38, humi: 90
[FlashDB][sample][tsdb] queried a TSL: time: 23, temp: 36, humi: 85
[FlashDB][sample][tsdb] queried a TSL: time: 24, temp: 38, humi: 90
[FlashDB][sample][tsdb] queried a TSL: time: 25, temp: 36, humi: 85
[FlashDB][sample][tsdb] queried a TSL: time: 26, temp: 38, humi: 90
[FlashDB][sample][tsdb] queried a TSL: time: 27, temp: 36, humi: 85
[FlashDB][sample][tsdb] queried a TSL: time: 28, temp: 38, humi: 90
[FlashDB][sample][tsdb] queried a TSL: time: 29, temp: 36, humi: 85
[FlashDB][sample][tsdb] queried a TSL: time: 30, temp: 38, humi: 90
[FlashDB][sample][tsdb] queried a TSL: time: 31, temp: 36, humi: 85
[FlashDB][sample][tsdb] queried a TSL: time: 32, temp: 38, humi: 90
[FlashDB][sample][tsdb] queried a TSL: time: 33, temp: 36, humi: 85
[FlashDB][sample][tsdb] queried a TSL: time: 34, temp: 38, humi: 90
[FlashDB][sample][tsdb] queried a TSL: time: 35, temp: 36, humi: 85
[FlashDB][sample][tsdb] queried a TSL: time: 36, temp: 38, humi: 90
[FlashDB][sample][tsdb] queried a TSL: time: 37, temp: 36, humi: 85
[FlashDB][sample][tsdb] queried a TSL: time: 38, temp: 38, humi: 90
[FlashDB][sample][tsdb] queried a TSL: time: 39, temp: 36, humi: 85
[FlashDB][sample][tsdb] queried a TSL: time: 40, temp: 38, humi: 90
[FlashDB][sample][tsdb] queried a TSL: time: 41, temp: 36, humi: 85
[FlashDB][sample][tsdb] queried a TSL: time: 42, temp: 38, humi: 90
[FlashDB][sample][tsdb] queried a TSL: time: 43, temp: 36, humi: 85
[FlashDB][sample][tsdb] queried a TSL: time: 44, temp: 38, humi: 90
[FlashDB][sample][tsdb] queried a TSL: time: 45, temp: 36, humi: 85
[FlashDB][sample][tsdb] queried a TSL: time: 46, temp: 38, humi: 90
[FlashDB][sample][tsdb] queried a TSL: time: 1, temp: 36, humi: 85
[FlashDB][sample][tsdb] queried a TSL: time: 2, temp: 38, humi: 90
[FlashDB][sample][tsdb] queried a TSL: time: 3, temp: 36, humi: 85
[FlashDB][sample][tsdb] queried a TSL: time: 4, temp: 38, humi: 90
[FlashDB][sample][tsdb] queried a TSL: time: 5, temp: 36, humi: 85
[FlashDB][sample][tsdb] queried a TSL: time: 6, temp: 38, humi: 90
[FlashDB][sample][tsdb] queried a TSL: time: 7, temp: 36, humi: 85
[FlashDB][sample][tsdb] queried a TSL: time: 8, temp: 38, humi: 90
[FlashDB][sample][tsdb] queried a TSL: time: 9, temp: 36, humi: 85
[FlashDB][sample][tsdb] queried a TSL: time: 10, temp: 38, humi: 90
[FlashDB][sample][tsdb] queried a TSL: time: 11, temp: 36, humi: 85
[FlashDB][sample][tsdb] queried a TSL: time: 12, temp: 38, humi: 90
[FlashDB][sample][tsdb] queried a TSL: time: 13, temp: 36, humi: 85
[FlashDB][sample][tsdb] queried a TSL: time: 14, temp: 38, humi: 90
[FlashDB][sample][tsdb] queried a TSL: time: 15, temp: 36, humi: 85
[FlashDB][sample][tsdb] queried a TSL: time: 16, temp: 38, humi: 90
[FlashDB][sample][tsdb] queried a TSL: time: 17, temp: 36, humi: 85
[FlashDB][sample][tsdb] queried a TSL: time: 18, temp: 38, humi: 90
[FlashDB][sample][tsdb] queried a TSL: time: 19, temp: 36, humi: 85
[FlashDB][sample][tsdb] queried a TSL: time: 20, temp: 38, humi: 90
[FlashDB][sample][tsdb] queried a TSL: time: 21, temp: 36, humi: 85
[FlashDB][sample][tsdb] queried a TSL: time: 22, temp: 38, humi: 90
[FlashDB][sample][tsdb] queried a TSL: time: 23, temp: 36, humi: 85
[FlashDB][sample][tsdb] queried a TSL: time: 24, temp: 38, humi: 90
[FlashDB][sample][tsdb] queried a TSL: time: 25, temp: 36, humi: 85
[FlashDB][sample][tsdb] queried a TSL: time: 26, temp: 38, humi: 90
[FlashDB][sample][tsdb] queried a TSL: time: 27, temp: 36, humi: 85
[FlashDB][sample][tsdb] queried a TSL: time: 28, temp: 38, humi: 90
[FlashDB][sample][tsdb] queried a TSL: time: 29, temp: 36, humi: 85
[FlashDB][sample][tsdb] queried a TSL: time: 30, temp: 38, humi: 90
[FlashDB][sample][tsdb] queried a TSL: time: 31, temp: 36, humi: 85
[FlashDB][sample][tsdb] queried a TSL: time: 32, temp: 38, humi: 90
[FlashDB][sample][tsdb] queried a TSL: time: 33, temp: 36, humi: 85
[FlashDB][sample][tsdb] queried a TSL: time: 34, temp: 38, humi: 90
[FlashDB][sample][tsdb] queried a TSL: time: 35, temp: 36, humi: 85
[FlashDB][sample][tsdb] queried a TSL: time: 36, temp: 38, humi: 90
[FlashDB][sample][tsdb] queried a TSL: time: 37, temp: 36, humi: 85
[FlashDB][sample][tsdb] queried a TSL: time: 38, temp: 38, humi: 90
[FlashDB][sample][tsdb] queried a TSL: time: 39, temp: 36, humi: 85
[FlashDB][sample][tsdb] queried a TSL: time: 40, temp: 38, humi: 90
[FlashDB][sample][tsdb] queried a TSL: time: 41, temp: 36, humi: 85
[FlashDB][sample][tsdb] queried a TSL: time: 42, temp: 38, humi: 90
[FlashDB][sample][tsdb] queried a TSL: time: 43, temp: 36, humi: 85
[FlashDB][sample][tsdb] queried a TSL: time: 44, temp: 38, humi: 90
[FlashDB][sample][tsdb] queried a TSL: time: 45, temp: 36, humi: 85
[FlashDB][sample][tsdb] queried a TSL: time: 46, temp: 38, humi: 90
[FlashDB][sample][tsdb] query count is: 2
[FlashDB][sample][tsdb] set the TSL (time 1) status from 3 to 3
[FlashDB][sample][tsdb] set the TSL (time 2) status from 3 to 3
[FlashDB][sample][tsdb] set the TSL (time 3) status from 3 to 3
[FlashDB][sample][tsdb] set the TSL (time 4) status from 3 to 3
[FlashDB][sample][tsdb] set the TSL (time 5) status from 3 to 3
[FlashDB][sample][tsdb] set the TSL (time 6) status from 3 to 3
[FlashDB][sample][tsdb] set the TSL (time 7) status from 3 to 3
[FlashDB][sample][tsdb] set the TSL (time 8) status from 3 to 3
[FlashDB][sample][tsdb] set the TSL (time 9) status from 3 to 3
[FlashDB][sample][tsdb] set the TSL (time 10) status from 3 to 3
[FlashDB][sample][tsdb] set the TSL (time 11) status from 3 to 3
[FlashDB][sample][tsdb] set the TSL (time 12) status from 3 to 3
[FlashDB][sample][tsdb] set the TSL (time 13) status from 3 to 3
[FlashDB][sample][tsdb] set the TSL (time 14) status from 3 to 3
[FlashDB][sample][tsdb] set the TSL (time 15) status from 3 to 3
[FlashDB][sample][tsdb] set the TSL (time 16) status from 3 to 3
[FlashDB][sample][tsdb] set the TSL (time 17) status from 3 to 3
[FlashDB][sample][tsdb] set the TSL (time 18) status from 3 to 3
[FlashDB][sample][tsdb] set the TSL (time 19) status from 3 to 3
[FlashDB][sample][tsdb] set the TSL (time 20) status from 3 to 3
[FlashDB][sample][tsdb] set the TSL (time 21) status from 3 to 3
[FlashDB][sample][tsdb] set the TSL (time 22) status from 3 to 3
[FlashDB][sample][tsdb] set the TSL (time 23) status from 3 to 3
[FlashDB][sample][tsdb] set the TSL (time 24) status from 3 to 3
[FlashDB][sample][tsdb] set the TSL (time 25) status from 3 to 3
[FlashDB][sample][tsdb] set the TSL (time 26) status from 3 to 3
[FlashDB][sample][tsdb] set the TSL (time 27) status from 3 to 3
[FlashDB][sample][tsdb] set the TSL (time 28) status from 3 to 3
[FlashDB][sample][tsdb] set the TSL (time 29) status from 3 to 3
[FlashDB][sample][tsdb] set the TSL (time 30) status from 3 to 3
[FlashDB][sample][tsdb] set the TSL (time 31) status from 3 to 3
[FlashDB][sample][tsdb] set the TSL (time 32) status from 3 to 3
[FlashDB][sample][tsdb] set the TSL (time 33) status from 3 to 3
[FlashDB][sample][tsdb] set the TSL (time 34) status from 3 to 3
[FlashDB][sample][tsdb] set the TSL (time 35) status from 3 to 3
[FlashDB][sample][tsdb] set the TSL (time 36) status from 3 to 3
[FlashDB][sample][tsdb] set the TSL (time 37) status from 3 to 3
[FlashDB][sample][tsdb] set the TSL (time 38) status from 3 to 3
[FlashDB][sample][tsdb] set the TSL (time 39) status from 3 to 3
[FlashDB][sample][tsdb] set the TSL (time 40) status from 3 to 3
[FlashDB][sample][tsdb] set the TSL (time 41) status from 3 to 3
[FlashDB][sample][tsdb] set the TSL (time 42) status from 3 to 3
[FlashDB][sample][tsdb] set the TSL (time 43) status from 3 to 3
[FlashDB][sample][tsdb] set the TSL (time 44) status from 3 to 3
[FlashDB][sample][tsdb] set the TSL (time 45) status from 2 to 3
[FlashDB][sample][tsdb] set the TSL (time 46) status from 2 to 3
Restarting in 1000 seconds...
Restarting in 999 seconds...
Restarting in 998 seconds...
Restarting in 997 seconds...
Restarting in 996 seconds...
Restarting in 995 seconds...
Restarting in 994 seconds...
Restarting in 993 seconds...
Restarting in 992 seconds...
Restarting in 991 seconds...
Restarting in 990 seconds...
Restarting in 989 seconds...
Restarting in 988 seconds...
Restarting in 987 seconds...
Restarting in 986 seconds...
Restarting in 985 seconds...
Restarting in 984 seconds...
Restarting in 983 seconds...
Restarting in 982 seconds...
Restarting in 981 seconds...
Restarting in 980 seconds...
Restarting in 979 seconds...
Restarting in 978 seconds...
Restarting in 977 seconds...
Restarting in 976 seconds...
Restarting in 975 seconds...
Restarting in 974 seconds...
Restarting in 973 seconds...
Restarting in 972 seconds...
Restarting in 971 seconds...
Restarting in 970 seconds...
Restarting in 969 seconds...
Restarting in 968 seconds...
Restarting in 967 seconds...
Restarting in 966 seconds...
Restarting in 965 seconds...
Restarting in 964 seconds...
Restarting in 963 seconds...
Restarting in 962 seconds...
Restarting in 961 seconds...
Restarting in 960 seconds...
Restarting in 959 seconds...
Restarting in 958 seconds...
Restarting in 957 seconds...
Restarting in 956 seconds...
Restarting in 955 seconds...

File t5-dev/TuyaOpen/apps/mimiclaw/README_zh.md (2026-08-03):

## 在涂鸦 T5AI 上运行 MimiClaw -  TuyaOpen 移植版

本项目是在 **涂鸦 T5AI 开发板** 以及可选的 **Linux 运行时** 上运行 MimiClaw 开源项目的 TuyaOpen 移植版，用于演示和开发 MimiClaw 风格的本地优先 AI 助手。  
插上电、连上 Wi‑Fi，这块几十块钱的 T5AI 板子就会变成一个可以 7×24 小时运行的超级 AI 管家。

你可以通过 **飞书 / Telegram / Discord** 直接和它对话，把任务丢给它处理；  
它支持 **DeepSeek、Claude、GPT、MiniMax 等主流大模型**，可以在不同模型和兼容接口之间灵活切换；  
它有本地记忆，所有对话和偏好都以纯文本文件保存在芯片里，重启不丢失，用得越久越懂你。

它还内置了 **定时任务调度器**，可以让 AI 自己安排每日提醒、定时汇总；  
内置 **心跳检测机制**，定时读取任务清单，自动唤醒执行任务——不需要你催，它自己会动。  

更重要的是，依托 TuyaOpen 丰富的 **驱动、显示和传感器外设能力**，它可以读取板载传感器、控制 GPIO，把 AI 真正“接到”各种硬件设备上——  
无论是 AI 台灯、逗宠机器人还是 AI 玩具，都可以快速拥有一个功能完整、可自我进化的 AI 管家。

**免责声明 / 商标说明**：本项目是社区维护的 TuyaOpen 移植版，用于在涂鸦 T5AI 硬件上运行 MimiClaw 开源项目，与涂鸦官方、MimiClaw 原始项目维护者以及文中提到的各大模型 / 平台均无隶属、合作或背书关系。“MimiClaw”、“OpenClaw”、“Telegram”、“Discord”、“飞书”等名称及商标归各自权利人所有。

---

## 与上游 MimiClaw 项目的差异

上游开源仓库：[`memovai/mimiclaw`](https://github.com/memovai/mimiclaw)

本项目基于上游 MimiClaw 开源项目实现，是一个面向 TuyaOpen 生态的第三方移植版，保留了其核心思想（嵌入式 Agent 循环、本地记忆、工具调用、定时任务与心跳机制），并针对 TuyaOpen 生态做了以下扩展和改造：

- **目标硬件与运行环境**
  - 新增对 **涂鸦 T5AI 开发板** 的一等公民支持，集成 TuyaOpen SDK、显示屏和硬件外设
  - 提供 **Linux Runtime**，方便在 PC / 云端调试、开发和快速验证 Agent 逻辑
- **对话通道**
  - 在原本 Telegram 的基础上，增加了 **飞书** 与 **Discord** 支持
  - 通过统一的 CLI 命令切换当前使用的社交通道
- **大模型配置方式**
  - 支持 **OpenAI**、**Anthropic** 与 **MiniMax**，同时支持 **兼容 OpenAI/Anthropic 协议的自建 / 第三方 URL**
  - 可通过命令行与 `mimi_secrets.h` 双层配置模型与 API
- **与 TuyaOpen 深度集成**
  - 利用 TuyaOpen 的 **驱动、传感器与显示能力**，让 AI 能够读取环境数据、控制 GPIO 以及更多硬件外设
  - 采用 TuyaOpen 的示例工程结构，位于 `apps/tuya_mimiclaw` 目录下，便于与其他示例一起管理和构建

关于 MimiClaw 自身的架构和实现细节，可参考上游仓库文档；本说明重点介绍 TuyaOpen 移植与使用方式。

---

## 迁移与配置说明

以下步骤默认你已经完成固件编译并烧录到板子（或已在 Linux Runtime 中启动进程）。  
通过串口工具以 **115200 波特率** 打开调试口，进入命令行界面。

### 1. 查看命令行工具

串口连接成功后，在命令行中输入：

```text
help
```

即可获取到当前固件支持的命令行工具列表和帮助信息。

### 2. 配置大模型（OpenAI / Anthropic / MiniMax / 兼容 URL）

你可以选择 `openai`、`anthropic` 或 `minimax` 作为模型提供方，也可以使用 **OpenAI / Anthropic 协议兼容的自建或第三方接口**。

典型配置流程：

1. 选择模型提供方：
   - `set_model_provider openai`
   - 或 `set_model_provider anthropic`
   - 或 `set_model_provider minimax`
2. 设置 API Key：
   - `set_api_key sk-xxxx...`
3. （可选）设置兼容的 API Base URL：
   - `set_api_url https://your-compatible-endpoint.example.com`
4. 设置模型名称：
   - `set_model gpt-4o`（或你所使用提供方支持的任意模型）
   - MiniMax 可选：`set_model MiniMax-M2.7` 或 `set_model MiniMax-M2.5-highspeed`（204K 上下文窗口）

如果你选择“兼容 URL”模式，**必须**同时设置 `API_KEY` 和 `API_URL`，缺一不可，否则接口调用会失败。

对应你原始提到的迁移说明，可以理解为：

1. **115200 打开烧录口，输入 `help`，可以获取到命令行工具**
2. **配置大模型，选择 `openai`、`anthropic` 或 `minimax`，然后输入 `API_KEY` 和 模型；如果使用兼容 URL，需要额外输入 `API_URL`**

### 3. 连接路由器（Wi‑Fi 配网）

使用命令行配置路由器 SSID 与密码：

```text
set_wifi <ssid> <password>
restart
```

执行 `restart` 后，设备会按新配置重启并重新连接网络。

对应你的迁移说明：

3. **连接路由器：`set_wifi xxx xxx` 设置路由器，设置完成后重启 `restart` 命令**

### 4. 切换社交账号 / 对话通道（Telegram / Discord / 飞书）

当前固件支持通过多种通道与 MimiClaw 对话：

- `telegram`
- `discord`
- `feishu`（飞书）

切换通道示例：

```text
set_channel_mode telegram
```

或：

```text
set_channel_mode feishu
```

或：

```text
set_channel_mode discord
```

根据所选通道，在命令行中输入对应的 `token` / `appid` / `secret` 等认证信息。完成配置后，同样需要重启：

```text
restart
```

对应你的迁移说明：

4. **切换社交账号目前支持 telegram/discord/feishu，`set_channel_mode telegram` 或者 `set_channel_mode feishu`，并根据相关账号要求输入 token/appid 等信息，设置完成后重启 `restart` 命令**

### 5. 使用 `mimi_secrets.h` 一次性配置（可选）

如果你更习惯在编译前一次性写好配置，可以直接复制示例文件：

```bash
cp apps/tuya_mimiclaw/mimi_secrets.h.example apps/tuya_mimiclaw/mimi_secrets.h
```

然后编辑 `mimi_secrets.h`，填入：

- Wi‑Fi 名称与密码
- 大模型 API Key、模型名称
- 模型提供方（OpenAI / Anthropic / MiniMax / 兼容 URL）
- 对话通道及必要的 Token / AppID 等

保存后重新编译并烧录固件即可。

对应你的迁移说明：

5. **也可以直接复制 `apps/tuy_mimiclaw/mimi_secrets.h.example` 并重命名为 `mimi_secrets.h` 修改文件上的配置，并重新编译**  
（本仓库中目录名为 `apps/tuya_mimiclaw`，请以实际路径为准）

6. **存储切换**
  
在 `apps/tuya_mimiclaw/mimi_config.h` 中

```
#if MIMI_USE_SDCARD
#define MIMI_FS_BASE "/spiffs"
#else
#define MIMI_FS_BASE "/spiffs"
#endif
```c

7. **搜索引擎切换**

在 `apps/tuya_mimiclaw/mimi_config.h` 中

```
/* Search Engine Selection: 0 = Brave, 1 = Baidu */
#ifndef MIMI_USE_BAIDU_SEARCH
#define MIMI_USE_BAIDU_SEARCH 0
#endif
```c

### 6. 配置优先级规则

配置优先级（从高到低）如下：

1. **命令行输入（CLI）**
2. `mimi_secrets.h` 中的编译期默认值

如果某个参数在命令行中已经设置，则总是优先生效；  
命令行中没有设置的参数会退回到 `mimi_secrets.h` 的默认值；  
如果两处都没有提供必要参数，则会导致对应功能报错或无法启动。

对应你的迁移说明：

6. **所有配置以命令行输入的优先级最高，命令行中没有的参数会采用 `mimi_secrets.h` 中的参数，否则就会报错**

---

## 支持的芯片 / 运行环境

| 名称           | 支持状态 | 说明                                          |
| -------------- | -------- | --------------------------------------------- |
| 涂鸦 T5AI 开发板 | 支持     | 主要嵌入式目标，使用 TuyaOpen SDK 与硬件栈。 |
| Linux Runtime  | 支持     | 直接在 Linux 主机上运行 Agent，用于开发调试。 |

---

## 致谢与版权说明

本项目深受上游开源项目 [`memovai/mimiclaw`](https://github.com/memovai/mimiclaw) 启发，并在其基础上进行移植与扩展。

上游 MimiClaw 项目展示了如何在一块 ESP32‑S3 小板上，以纯 C 代码实现：

- 不依赖 Linux / Node.js 的轻量级运行时
- 基于文本文件的本地记忆（如 `SOUL.md`、`USER.md`、`MEMORY.md` 等）
- 工具调用、定时任务（Cron）与心跳驱动的自主执行机制

本仓库在此基础上，将 MimiClaw 带入 **TuyaOpen 生态**：

- 适配涂鸦 T5AI 硬件、显示与外设
- 与 TuyaOpen 的 AI / IoT 工作流打通
- 扩展更多模型 / 通道选项，面向真实产品落地场景

上游 MimiClaw 采用 **MIT License** 授权；  
本项目在遵循其许可证的前提下进行二次开发，并在此对原作者及社区表示由衷感谢。

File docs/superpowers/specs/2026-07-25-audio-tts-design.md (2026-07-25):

# 赛博财神庙 · 声音功能设计（音效 + TTS 播报）

- 日期：2026-07-25
- 状态：设计定稿（待实施）
- 关联硬件：T5AI-Board + JST PH 1.25 2P 外接无源喇叭（GPIO28 PA 使能，已验证出声）

## 1. 目标

在现有 5 场景交互流程（待机→分类→问题→摇签→结果）上叠加两类声音，
增强仪式感与"赛博财神庙"氛围，且必须**全程可降级**：喇叭未接 / codec 失败 /
断网时，主流程（求签、显示、打印）零影响。

## 2. 两类声音

### 2.1 板端 8-bit 合成音效（离线，无素材文件）

代码实时合成正弦/噪声波形，编译进固件，走 `tdl_audio_play` 16K 单声道播放。
沿用像素 UI 风格，断网照常。

| 时机 | 场景钩子 | 音效 |
|---|---|---|
| 触发求签（轻触/摇 Stick） | 进入 SCENE_DRAW | 短促"叮" |
| 摇签动画进行中 | getting_lottery GIF | 签筒"沙沙"（噪声脉冲）|
| 出签瞬间 | lottery_get | 金币三音阶（C6-E6-G6，已实测）|
| 送打印 | 打印按钮回调 | 轻"滴" |

### 2.2 TTS 奶气萌娃播报（结果页自动播）

- **触发**：进入 SCENE_RESULT 且拿到签文后，异步请求，**不阻塞画面**。
- **文案**：`恭喜！第{N}签，{吉凶档位}！{四句签诗}……汪汪！`（约 15 秒）
- **声音**：火山语音合成大模型，voice_type = `zh_male_naiqimengwa_mars_bigtts`（奶气萌娃），结尾由 TTS 直接念"汪汪"。

## 3. 后端接口 `/api/fortune/tts`

- **入参**：`{ "text": "..." , "voice"?: "...", "encoding"?: "mp3|pcm" }`
  - `voice` 缺省取 `VOLC_TTS_VOICE`；`encoding` 缺省 `mp3`。
- **实现**：调火山 `https://openspeech.bytedance.com/api/v1/tts`
  - header `Authorization: Bearer;{token}`
  - body：`app{appid,token,cluster}` + `audio{voice_type,encoding,speed_ratio}` + `request{reqid,text,operation:"query"}`
  - 成功码 `code==3000`，`data` 为 base64 音频。
- **凭证**（服务器 `.env`，与 `ARK_API_KEY` 并列，不入代码）：
  `VOLC_TTS_APPID` / `VOLC_TTS_TOKEN` / `VOLC_TTS_CLUSTER=volcano_tts` / `VOLC_TTS_VOICE=zh_male_naiqimengwa_mars_bigtts`
- **返回给板端**：直接回传音频字节流（`Content-Type: audio/mpeg` 或裸 PCM），
  板端边收边解码播放。（MP3 需板端解码器；若板端解码不便，后端可直接返回 16K 单声道 PCM，见 §5 决策）

## 4. 板端播放链路

- 复用已建的 `fortune_audio` 模块（`tdl_audio` 句柄）。
- 结果页出现后，起一个后台任务：POST `/api/fortune/tts` → 收到音频 → 分块喂 `tdl_audio_play`。
- 失败（HTTP 错误/超时/codec 未就绪）→ 静默跳过，仅打日志。
- 音量默认 80%（`tdl_audio_volume_set`），现场可调。

## 5. 待定的实现级决策（实施时确认，不影响本设计）

1. **音频格式**：MP3（省带宽，需板端 MP3 解码，SDK 有 `ai_player`）vs 16K PCM（板端零解码，直接播，带宽大）。倾向 **PCM**：结果页文案短、局域网、实现最简。
2. **签诗是否逐字念全**：已定"签号+签诗"，约 15 秒。

## 6. 验收

- 后端：`curl /api/fortune/tts` 返回可播放音频；缺凭证时优雅报错。
- 板端：结果页出现 → 数秒内奶气萌娃念出签号+签诗+"汪汪"；断网/拔喇叭 → 无异常。
- 音效：四个时机各响一次，与动画同步。

## 7. 改动范围

- 后端：`core-engine/src` 新增 `/api/fortune/tts`（约 60 行）+ 配置读取。
- 板端：`fortune_audio.c/.h` 扩展（音效合成 + TTS 流播放，约 200 行）；各 scene 插播放调用。
- 容错：全部静默降级，主流程零影响。

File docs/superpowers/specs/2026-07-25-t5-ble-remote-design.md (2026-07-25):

# T5AI 侧 BLE 摇签接收设计（Stick 联动 · T5 侧）

日期：2026-07-25
状态：已确认设计，**暂缓实施**——等待 cyber-fortune-v2
（`2026-07-25-cyber-fortune-v2-design.md`）实施完成后单独排期，避免并行修改
`apps/cyber_fortune` 产生冲突。

## 背景

StickS3 摇签遥控器（见 `2026-07-25-sticks3-shake-draw-design.md`）通过无连接 BLE 广播
发送摇签事件。本 spec 描述 T5AI-Board（TuyaOpen `apps/cyber_fortune`）接收广播并触发
求签流程的改动。**通信协议以 Stick 侧 spec 第 1 节为共享契约，不得单方变更。**

## 交互语义（已与用户确认）

1. **两者并存**：触屏「求签」按钮保留，摇签事件等价触发；Stick 离线不影响触屏流程。
2. **全局响应**：待机页收到事件=求签；结果页收到事件=回待机并立即求签；求签动画中忽略。

## 改动内容

> 注意：以下基于 v2 实施前的代码结构（`fortune_ui.c` 的 `s_drawing`/`draw_btn_event_cb`），
> 实施时需对照 v2 落地后的实际结构做等价映射。

- 新增 `fortune_ble_remote.c/h`（约 150 行）：
  - `tal_ble_bt_init(TAL_BLE_ROLE_CENTRAL, cb)` + 常驻扫描（参考 `examples/ble/ble_central`）。
  - 扫描回调（非 LVGL 线程）：过滤厂商数据魔数 "CF" → 校验协议版本/事件类型 → 事件序号
    去重（与上次不同才触发）→ 置 `volatile` 触发标志。
- **线程安全**：UI 模块增加 **100ms LVGL 轮询 timer** 消费标志位；所有 UI 变更保持在
  LVGL 线程内，零跨线程调用。
- UI 模块新增公开函数 `fortune_ui_trigger_draw()`（全局响应语义）：
  - 待机页 → 等价点击求签按钮；
  - 结果页 → 回待机并立即开始求签；
  - 求签进行中（`s_drawing` 或 v2 中的等价状态）→ 忽略。
- `tuya_main.c`：UI 初始化完成后调用 `fortune_ble_remote_init()`；BLE 初始化失败仅打
  日志降级，触屏流程不受影响。
- `app_default.config`：启用蓝牙相关配置项（具体 Kconfig 符号实施时确认）。

## 容错

| 场景 | 行为 |
|---|---|
| Stick 没电/丢失/离场 | 触屏求签照常可用 |
| 广播包重复接收 | 事件序号去重，只触发一次 |
| 求签进行中收到事件 | 忽略 |
| BLE 初始化失败 | 打日志降级，主流程不受影响 |

## 测试计划

1. **单侧**：monitor 日志确认扫描、魔数过滤、序号去重、非 LVGL 线程零 UI 调用。
2. **端到端**：摇 Stick → 大屏出签 → 打印机出票；结果页摇动 → 重新求签。
3. **鲁棒性**：连续事件仅按冷却节奏出签；Stick 拔电重启后联动无需干预恢复。

## 假设

- T5AI 的 BLE 扫描与现有 WiFi/后端 HTTPS 请求共存无冲突（TuyaOpen 常规能力，实施时验证）。
- v2 实施可能重构 UI 状态机；本 spec 的触发语义不变，函数挂载点按 v2 实际结构调整。

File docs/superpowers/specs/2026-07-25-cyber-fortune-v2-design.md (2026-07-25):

# 赛博财神庙 v2 —— AI 互动求签固件重设计

日期：2026-07-25
状态：已确认（用户批准）
硬件：Tuya T5AI-Board + 3.5" ILI9488 LCD（GT1151 触摸）+ EM5820H USB 热敏打印机
代码位置：`t5-dev/TuyaOpen/apps/cyber_fortune`（重构现有 app）

## 概要

将现有"离线随机抽 60 支固定签"的单机固件，升级为"像素风动画 + 触屏问答 + 后端
LLM 生成个性化签文"的互动求签机。屏幕**横屏 480×320**，白底黑像素风格，联网调用
专用后端（core-engine，47.98.99.199:8000）生成签文，断网无缝切本地兜底签谱，
小票按需打印。

## 硬性约束

- **横屏**：UI 分辨率 480×320（现固件为竖屏 320×480，显示/触摸都需旋转 90°）。
- 视觉风格：白底 `#FFFFFF`、黑像素 `#000000`、8px 笔触边框；按钮按下反色；
  仅签级徽章允许红色点缀（呼应签筒 GIF 的红色）。
- 签文内容为 AI 原创白话，不使用成语典故故事。
- 交互为混合模式：触屏选类别 + 1 轮预写追问选择题；语音留二期。

## 场景状态机

```
[开机] WiFi 连接 + USB host 上电 + 打印机 worker 初始化
   │  开机首屏：opening_1（彩色版，缩放后）停留约 3s
   ▼
┌─ 待机页 ◀─────────────────────────────────────┐
│  opening_2~6.gif 随机轮播；底部提示"轻触屏幕 求一签"；    │
│  角落像素 WiFi 图标示意在线状态                        │
└── 点击任意处 ──▶ 类别页                              │
      吉祥物问"想问点什么？"                             │
      6 宫格：财运 / 事业 / 姻缘 / 学业 / 健康 / 今日运势   │
      30s 无操作 ────────────────────────────────────┘
      点类别 ──▶ 追问页
            本地题库按类别随机抽 1 题（3~4 个选项）
            点选项 ──▶ 思考/摇签页（两件事并行）
                  ├─ 立刻 POST 后端（10s 超时 → 本地兜底）
                  └─ thinking.gif（保底 2s）
                     → getting_lottery.gif（摇签）
                     → lottery_get.gif（出签）
            签文就绪且动画播完 ──▶ 结果页
                  签级徽章 + 原创白话诗(四句) + 针对性解签 + 行动建议
                  按钮：[打印签文] [再求一签]
                  打印后按钮变"已出票"防连点
                  60s 无操作 → 回待机
```

关键机制：**网络请求与摇签动画并行**。动画序列本身是等待遮罩——网络快时用户
零感知等待，慢时动画自然撑满 10s 超时窗口；超时或报错后无缝切兜底签文，
动画流程不变，用户无感知。

## UI 规范

- 中文字体：开源像素字体 **Fusion Pixel（缝合像素，12px 网格）**，
  ×2 渲染 24px 正文、×3 渲染 36px 标题，与 GIF 线条风格统一。
- **动态汉字覆盖**（关键技术点，三层保险）：
  1. LCD 字库按 GB2312 一级字库（3755 常用字 + ASCII + 标点）生成 LVGL 1bpp
     字体，两个字号合计约 500KB flash；
  2. 打印机 Unicode→GBK 映射表扩到 GB2312 全量（约 35KB）；
  3. 后端 prompt 约束"只用常用字"，服务端再把落在字库外的生僻字替换为常用同义字。

## GIF 资源管线

素材目录：`/Users/oliver/data/projects/moneyGod/scene_change_gifs/`

| 文件 | 用途 | 处理 |
|---|---|---|
| opening_1_01.gif (1536×1024, 彩色) | 开机首屏 | 缩放到 480×320 |
| opening_2~6_01.gif (480×320) | 待机轮播 | 直接用 |
| thinking.gif (480×320) | AI 思考 | 直接用 |
| getting_lottery.gif (1016×677, 彩色) | 摇签 | 缩放到 480×320 |
| lottery_get.gif (480×320) | 出签 | 直接用 |

- 离线预处理：统一 480×320、色板压到 ≤8 色，转 C 数组编进固件，`lv_gif` 播放。
- 解码画布约 300KB 放 PSRAM（充裕）；素材压完预计 ~2MB flash，实现阶段核实
  app 分区余量，超限则降帧率或删减 opening 变体。

### GIF 播放编排（已确认）

实测节拍：opening_1 = 3帧/0.6s；opening_2~6 = 各10帧/4.0s；thinking = 10帧/4.0s；
getting_lottery = 4帧/1.2s；lottery_get = 9帧/1.8s。

核心原则：**等待弹性全部吃在 thinking 段；摇签→出签为固定节奏收尾，
每次求签的高潮节拍恒定，不受网络抖动影响。**

```
开机     opening_1 循环 5 遍（3s，后台并行连 WiFi / 起 USB host）→ 待机
待机     opening_2~6 洗牌轮播：随机排列 5 支各播一遍(4s)，播完重新洗牌
         （不连续重复；20s 内五种动作全部出现）
类别页/追问页   无 GIF，静态像素 UI（吉祥物定格帧 + 对话气泡）
思考/摇签页：
  ① thinking         弹性段：最少 1 整遍(4s)，之后每帧(400ms)检查签文
                      是否就绪；就绪（或 10s 超时切兜底）即退出
  ② getting_lottery  固定 2 遍(2.4s) —— 摇签仪式
  ③ lottery_get      1 遍(1.8s) + 末帧定格 0.5s —— 出签悬念
结果页   无 GIF，纯像素排版
```

- 最短动画链 ≈ 8.7s，覆盖 LLM 典型延迟（3~8s），绝大多数情况用户体感零等待。
- **再求一签 → 直接回类别页**（不回待机）；任何超时返回 → 硬切回待机轮播。
- 全程仅一个 `lv_gif` 对象，切段换源，解码画布只占一份。

## 后端接口（core-engine 新增路由）

```
POST /api/fortune/draw
请求: { device_id, category, question, answer }
响应: { lot_no, grade, grade_score(1-5), poem(四句), explanation, advice }
```

- 签级由后端**加权随机先定**：上上 15% / 上 30% / 中 35% / 下 15% / 下下 5%；
  再让 LLM 按已定签级、围绕"类别 + 用户处境"写诗和解签。
- Prompt 要求：白话原创、不用典故成语故事、直接回应用户选择的处境、只用常用字。
- 简单 token 鉴权（专机专用）；LLM 侧超时预算 8s（板端总超时 10s）。

## 网络与兜底

- WiFi 凭据硬编码在配置头文件（专机摆摊场景足够）。
- 兜底签谱：6 类别 × 5 签级，每格预写 1~2 条（约 40 条，AI 批量初稿 + 人工过审），
  存固件；断网/超时时本地按同样权重摇签级后取对应文案，流程与动画完全一致。

## 打印

- 复用现有 worker 线程 + ESC/POS 管线（UTF-8→GBK、双倍字号标题、走纸）。
- 票面：店名头 → 第 X 签·签级 → 诗 → 解签 → 行动建议 → 落款"诚心求签 运随心转"。
- 触发方式：结果页 [打印签文] 按钮，按需打印；打完置灰为"已出票"。

## 代码结构

```
apps/cyber_fortune/src/
  tuya_main.c          启动（基本沿用：板级注册、USB host、LVGL 启动）
  fortune_flow.c       场景状态机 + 会话数据（本次类别/回答/签文）
  fortune_net.c        WiFi 连接 + HTTP 客户端 + JSON 解析
  fortune_fallback.c   兜底签谱数据 + 本地加权摇级
  fortune_question.c   追问题库（每类别 3~5 个变体）
  scene_standby.c      待机页（GIF 轮播）
  scene_category.c     类别页（6 宫格）
  scene_question.c     追问页
  scene_draw.c         思考/摇签/出签动画页
  scene_result.c       结果页 + 打印按钮
  fortune_printer.c    打印（票面改版 + 全量 GBK 表）
  assets/              GIF C 数组 + 像素字体 C 文件
```

旧的 `fortune_ui.c`、`qianpu_data.c`（60 签数据）、`font_cn_22/30.c`（窄字库）
在重构中移除或替换。

## 测试计划

1. 后端：curl 单测新接口（正常、超时、生僻字替换用例）。
2. 固件：先走纯兜底路径（不联网）跑通"待机→类别→追问→动画→结果→打印"全流程。
3. 联网对接真后端，验证并行动画/超时切换。
4. 真机验收：横屏显示与触摸坐标、GIF 帧率、EM5820H 出票。

## 已确认的决策记录

| 决策点 | 结论 |
|---|---|
| 输入方式 | 混合：触屏类别 + AI 追问选择题（语音二期） |
| 追问轮数 | 1 轮 |
| 追问来源 | 本地预写题库 |
| 签文结构 | 保留签形式，内容现代化（签级+原创白话诗+针对解签+行动建议） |
| 断网处理 | 本地兜底签谱，无缝切换，用户无感知 |
| 打印触发 | 结果页按钮，按需打印 |
| 类别 | 财运/事业/姻缘/学业/健康/今日运势（6 宫格） |
| 像素字体 | Fusion Pixel（缝合像素） |
| 屏幕方向 | **横屏 480×320（硬性要求）** |

## 二期候选（本期不做）

- 语音问签（板载麦克风 + 后端 ASR/TTS）
- 追问题库放后端可热更新
- WiFi 配网界面（替代硬编码凭据）

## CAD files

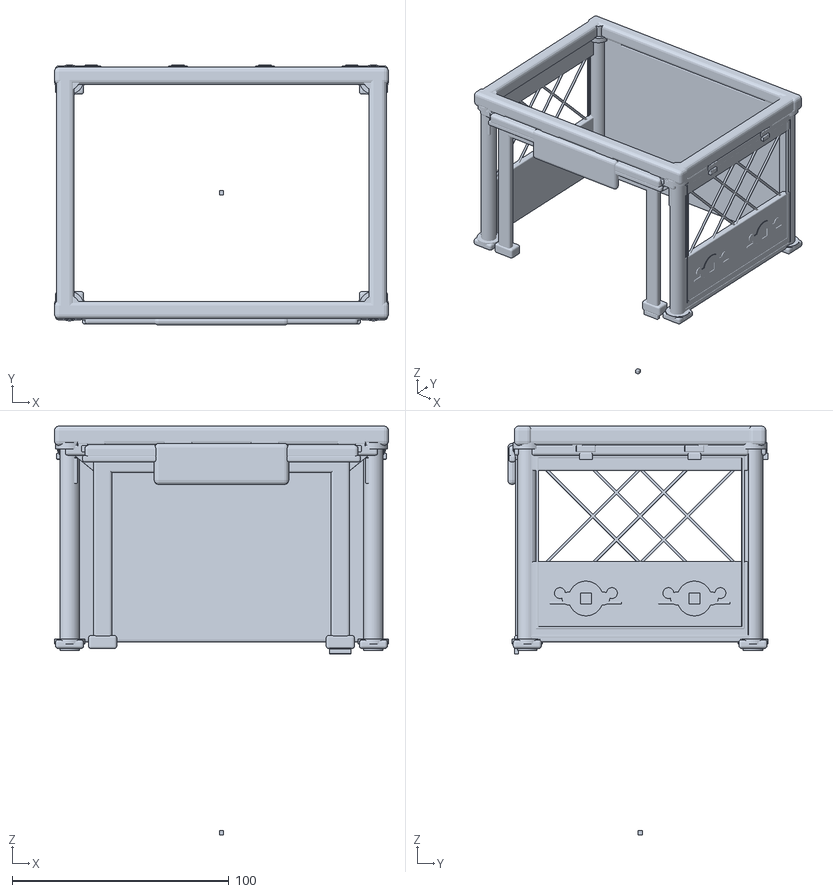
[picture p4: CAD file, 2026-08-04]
hardware/3d-models/0303.stl
154.0 x 120.0 x 188.5

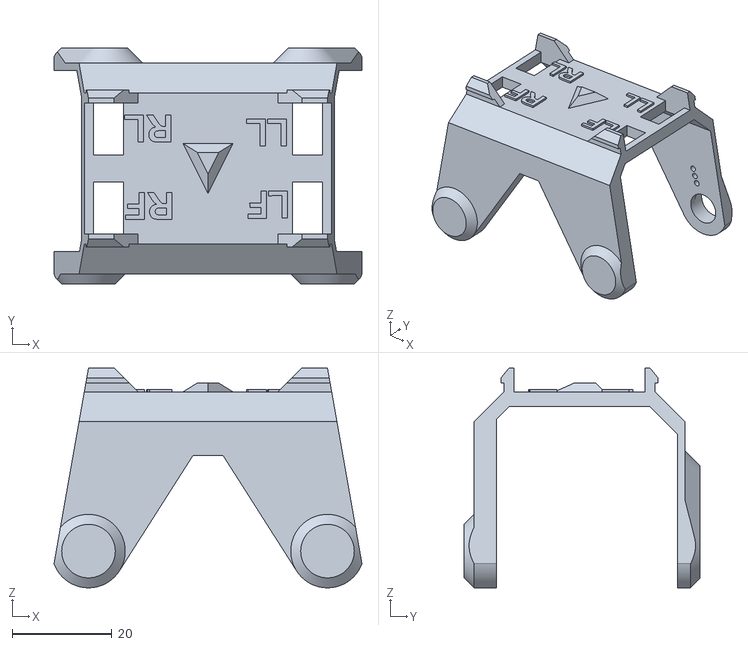
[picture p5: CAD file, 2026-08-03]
t5-dev/TuyaOpen/apps/tuya.ai/your_otto_robot/src/otto_ninja/3D_Models/胯部.stl
61.9 x 47.4 x 44.1

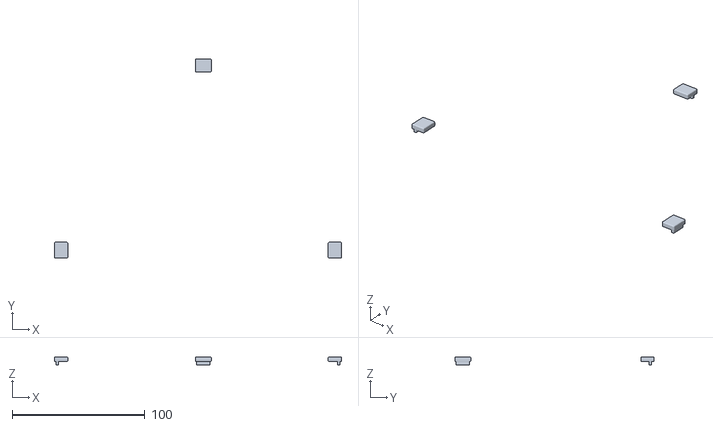
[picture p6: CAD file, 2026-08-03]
hardware/3d-models/0302.stl
216.0 x 150.0 x 6.05

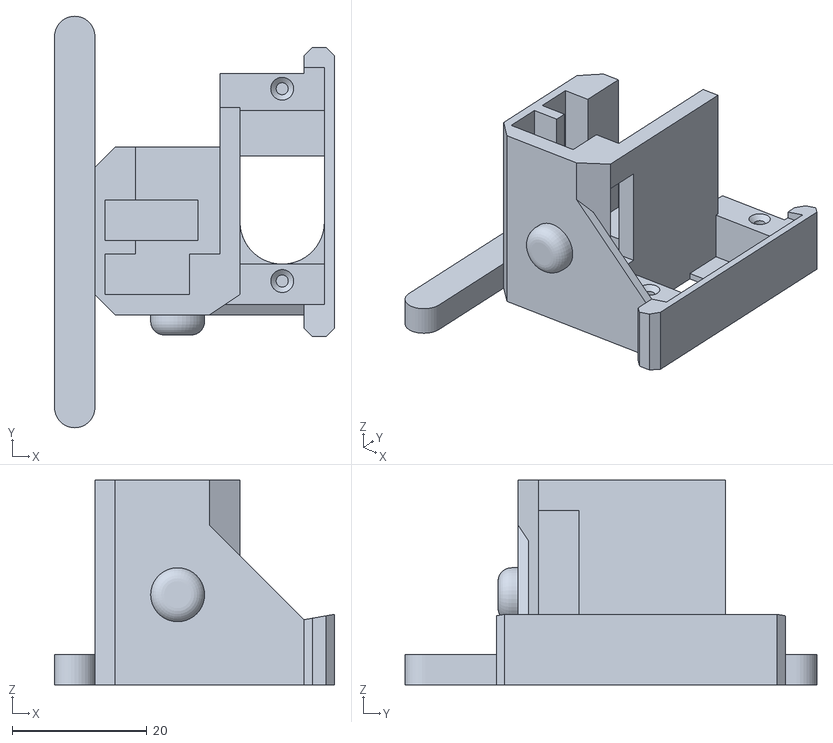
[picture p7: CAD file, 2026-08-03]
t5-dev/TuyaOpen/apps/tuya.ai/your_otto_robot/src/otto_ninja/3D_Models/左腿固定架.stl
41.5 x 61.0 x 30.4

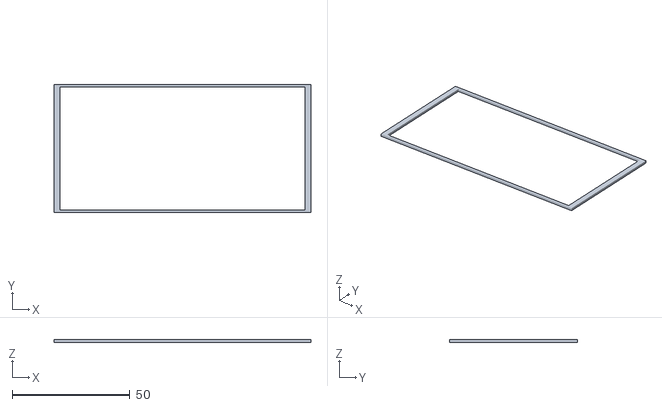
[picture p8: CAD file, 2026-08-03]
hardware/3d-models/16_printer_bracket.stl
109.0 x 54.5 x 1.20

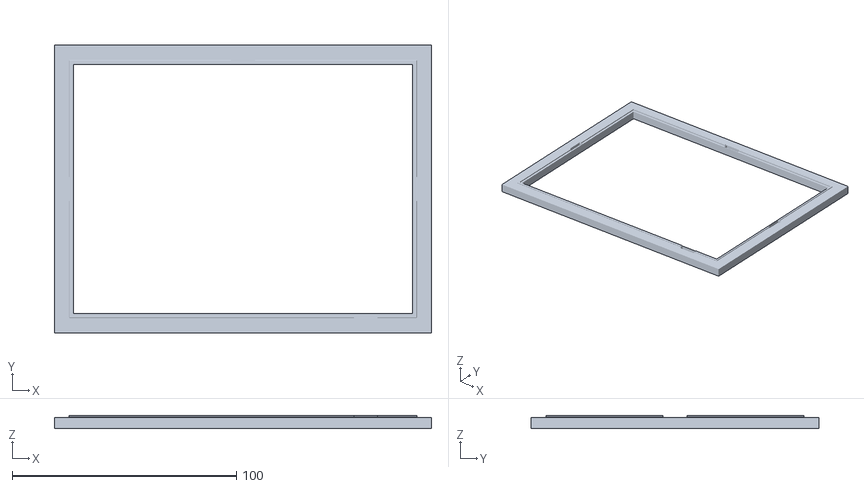
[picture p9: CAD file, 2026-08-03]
hardware/3d-models/04.stl
168.1 x 128.4 x 5.95

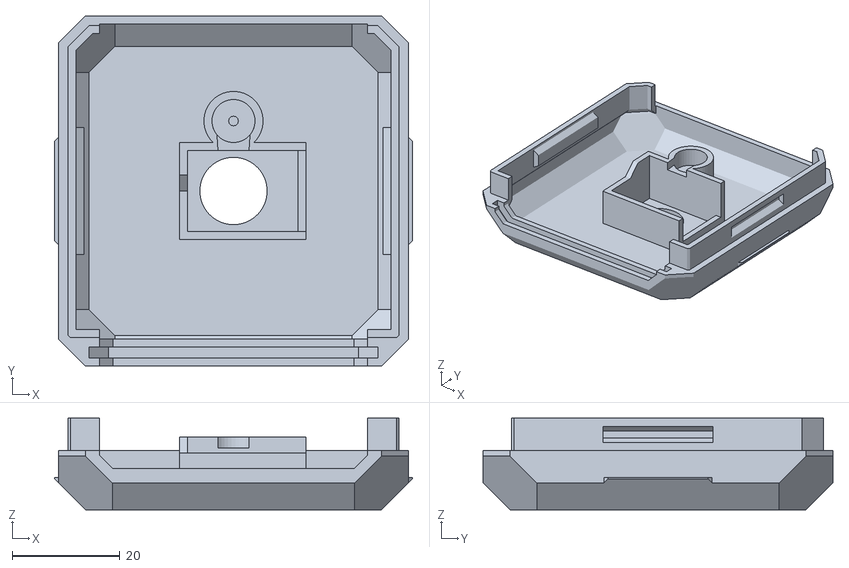
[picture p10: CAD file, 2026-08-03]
t5-dev/TuyaOpen/apps/tuya.ai/your_otto_robot/src/otto_ninja/3D_Models/顶部.stl
66.5 x 65.0 x 17.0

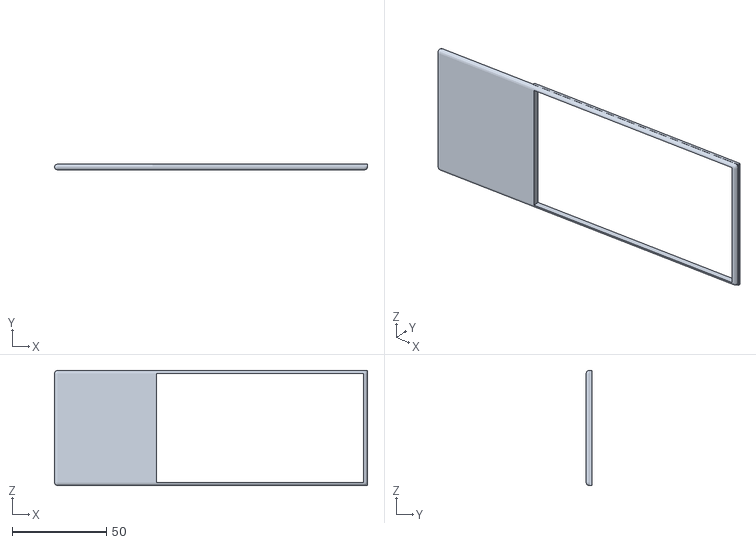
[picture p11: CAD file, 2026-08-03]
hardware/3d-models/18_rear_cover.stl
166.0 x 3.00 x 61.0

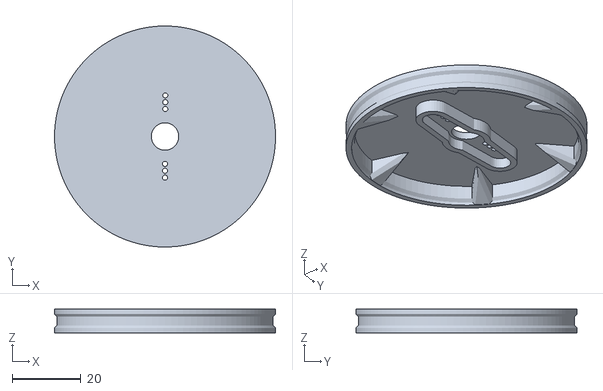
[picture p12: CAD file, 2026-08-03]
t5-dev/TuyaOpen/apps/tuya.ai/your_otto_robot/src/otto_ninja/3D_Models/右脚-new.stl
64.5 x 64.5 x 7.00

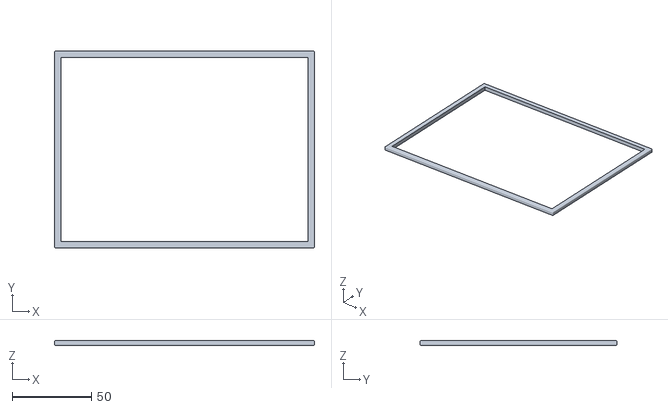
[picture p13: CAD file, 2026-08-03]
hardware/3d-models/0301.stl
164.0 x 124.0 x 3.00

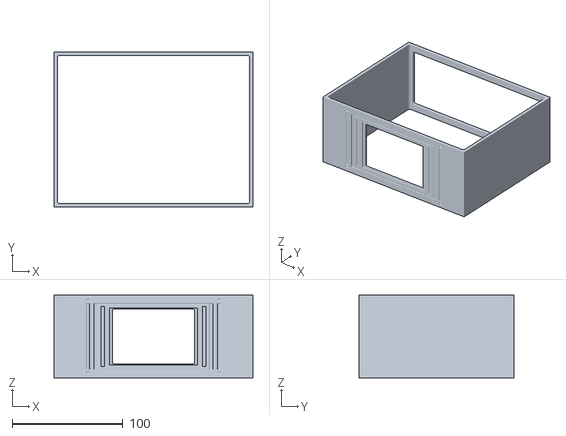
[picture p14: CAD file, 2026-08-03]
hardware/3d-models/11_base_shell.stl
180.0 x 140.0 x 75.0

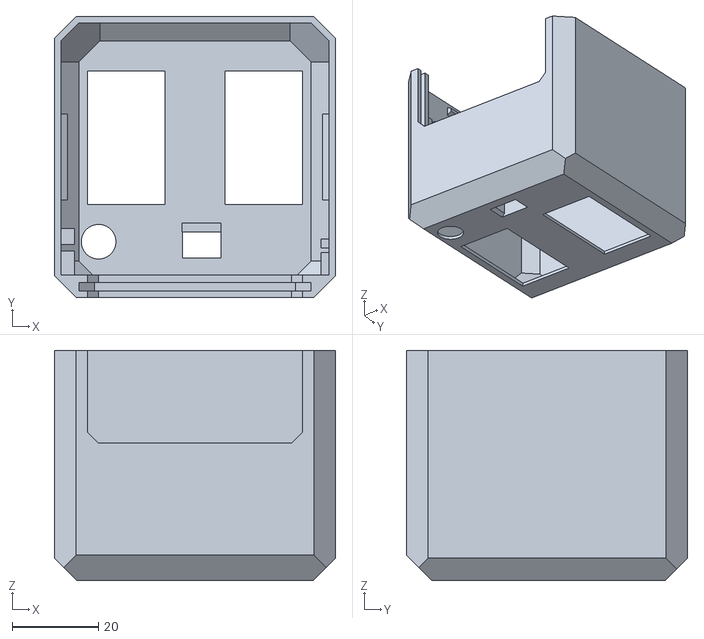
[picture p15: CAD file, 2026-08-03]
t5-dev/TuyaOpen/apps/tuya.ai/your_otto_robot/src/otto_ninja/3D_Models/头部.stl
65.0 x 65.0 x 53.2

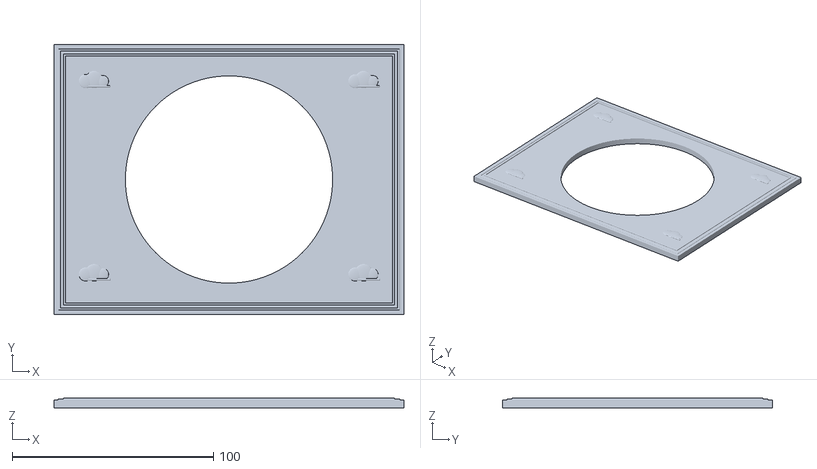
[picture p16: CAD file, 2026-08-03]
hardware/3d-models/08_top_platform.stl
174.0 x 134.0 x 4.95

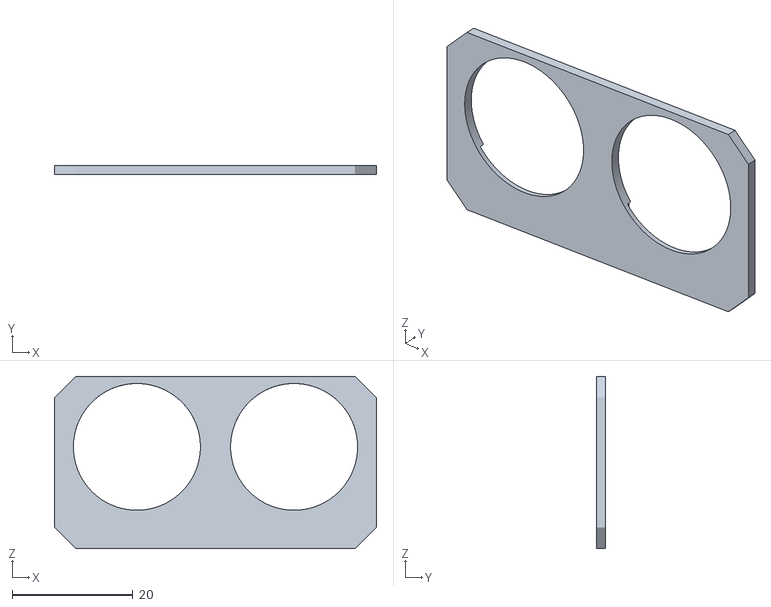
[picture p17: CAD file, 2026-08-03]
t5-dev/TuyaOpen/apps/tuya.ai/your_otto_robot/src/otto_ninja/3D_Models/眼睛.stl
53.3 x 1.50 x 28.5

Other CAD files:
t5-dev/TuyaOpen/apps/tuya.ai/your_otto_robot/src/otto_ninja/3D_Models/右腿固定架.stl
t5-dev/TuyaOpen/apps/tuya.ai/your_otto_robot/src/otto_ninja/3D_Models/左脚-new.stl
hardware/3d-models/02_roof_liner.stl
hardware/3d-models/13_display_bracket.stl
hardware/3d-models/09_maglev_ring.stl
hardware/3d-models/19_bottom_plate.stl

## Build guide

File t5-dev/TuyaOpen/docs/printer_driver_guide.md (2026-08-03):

# 打印机驱动使用指南

本文档描述 TuyaOpen 打印机模块的架构、接口和使用方法。

---

## 1. 模块架构

打印机模块分三层：

```
应用层
  ├─ tdl_printer_send_text()     文字打印（编码自动转换）
  ├─ tdl_printer_send_bitmap()   图片打印（协议自动适配）
  ├─ tdl_printer_send()          原始字节发送
  ├─ tdl_printer_start() / end() 打印任务控制
  ├─ tdl_printer_paper_feed()    进纸
  └─ tdl_printer_open() / close() 设备管理

TDL 层（src/peripherals/printer/tdl_printer/）
  协议适配：ESC/POS 命令生成，UTF-8→GBK 转换，位图裁剪

TDD 层（src/peripherals/printer/tdd_printer/）
  硬件驱动：UART / GPIO / SPI / PWM 操作
```

---

## 2. 已支持驱动

| 驱动 | 文件 | 协议 | 编码 | 接口类型 |
|---|---|---|---|---|
| DP-48A 热敏打印机 | `tdd_printer_dp48.c` | ESC/POS | GBK | UART |
| 通用 UART 打印机 | `tdd_printer_uart.c` | RAW | NONE | UART |
| MTP02-DXD 打印机构 | `tdd_printer_mtp02.c` | RAW | NONE | GPIO/SPI/PWM |

---

## 3. DP-48A 打印机驱动

### 3.1 硬件规格

| 参数 | 值 |
|---|----|
| 通信接口 | UART |
| 默认波特率 | 19200 bps |
| 打印宽度 | 384 dots（48mm） |
| 协议 | ESC/POS |
| 文字编码 | GBK（内部支持 GB18030） |
| 图片格式 | 1-bit 单色位图，`GS v 0` 命令 |

### 3.2 注册驱动

```c
#include "tdd_printer_dp48.h"
#include "tal_uart.h"

TDD_PRINTER_DP48_CFG_T dp48_cfg = {
    .port_id  = TUYA_UART_NUM_2,
    .uart_cfg = {
        .baudrate  = 19200,
        .databits  = TUYA_UART_DATA_LEN_8BIT,
        .stopbits  = TUYA_UART_STOP_LEN_1BIT,
        .parity    = TUYA_UART_PARITY_TYPE_NONE,
        .flowctrl  = TUYA_UART_FLOWCTRL_NONE,
    },
};

tdd_printer_dp48_register("dp48", &dp48_cfg);
```

### 3.3 Kconfig 配置

```
CONFIG_ENABLE_PRINTER=y
CONFIG_ENABLE_PRINTER_DP48=y
CONFIG_PRINTER_NAME="dp48"
```

---

## 4. 使用示例

### 4.1 初始化流程

```c
#include "tdl_printer_manage.h"

TDL_PRINTER_HANDLE printer;

// 1. 注册驱动（在系统初始化阶段）
tdd_printer_dp48_register("dp48", &dp48_cfg);

// 2. 查找打印机
tdl_printer_find("dp48", &printer);

// 3. 打开打印机（可选：注册事件回调）
TDL_PRINTER_OPEN_PARAM_T param = {
    .event_cb       = my_printer_event_cb,
    .event_cb_arg   = NULL,
    .poll_interval_ms = 500,
};
tdl_printer_open(printer, &param);
```

### 4.2 打印文字（UTF-8 输入）

```c
// 应用层始终传 UTF-8，TDL 自动转换为 GBK 发给 DP48A
tdl_printer_send_text(printer, "你好，世界！\r\n");
tdl_printer_send_text(printer, "Hello, TuyaOpen!\r\n");
```

### 4.3 发送 ESC/POS 命令

通过 `tdl_printer_send()` 发送原始 ESC/POS 命令字节：

```c
// 初始化打印机（ESC @）
uint8_t init_cmd[] = {0x1B, 0x40};
tdl_printer_send(printer, init_cmd, sizeof(init_cmd));

// 居中对齐（ESC a 1）
uint8_t center_cmd[] = {0x1B, 0x61, 0x01};
tdl_printer_send(printer, center_cmd, sizeof(center_cmd));

// 加粗开（ESC E 1）
uint8_t bold_on[] = {0x1B, 0x45, 0x01};
tdl_printer_send(printer, bold_on, sizeof(bold_on));

// 打印文字
tdl_printer_send_text(printer, "涂鸦智能\r\n");

// 加粗关
uint8_t bold_off[] = {0x1B, 0x45, 0x00};
tdl_printer_send(printer, bold_off, sizeof(bold_off));

// 进纸 3 行（ESC d 3）
uint8_t feed_cmd[] = {0x1B, 0x64, 0x03};
tdl_printer_send(printer, feed_cmd, sizeof(feed_cmd));

// 切纸（GS V 0）
uint8_t cut_cmd[] = {0x1D, 0x56, 0x00};
tdl_printer_send(printer, cut_cmd, sizeof(cut_cmd));
```

### 4.4 打印图片

```c
// 图片要求：1-bit 单色位图，行优先，MSB 在前
// 每行 (width + 7) / 8 字节

// 示例：8x8 笑脸
const uint8_t smiley[] = {
    0x3C, 0x42, 0xA5, 0x81,
    0xA5, 0x99, 0x42, 0x3C,
};

// 居中打印：x = (384 - 8) / 2 = 188
tdl_printer_send_bitmap(printer, 188, 8, 8, smiley);

// 靠左打印：x = 0
tdl_printer_send_bitmap(printer, 0, 8, 8, smiley);
```

**裁剪规则**：
- 若 `x >= 384`：静默不打印，返回 OK
- 若 `x + width > 384`：右侧超出部分静默裁剪
- 若 `width < 384`：仅打印图片宽度，右侧留白

### 4.5 打印任务控制（适用于 MTP02）

对于 UART 类打印机（DP48A），`start`/`end` 接口返回 `OPRT_NOT_SUPPORTED`，直接使用 `send`/`send_text`/`send_bitmap` 即可。

```c
// MTP02 流程（DP48A 不需要）
tdl_printer_start(printer);
tdl_printer_send(printer, dot_bitmap, len);
tdl_printer_end(printer);   // 自动进纸+停机
```

### 4.6 状态监控回调

```c
void my_printer_event_cb(TDL_PRINTER_HANDLE handle,
                         TDL_PRINTER_EVENT_E event,
                         void *data, void *arg)
{
    switch (event) {
    case TDL_PRINTER_EVENT_PAPER_OUT:
        PR_WARN("打印机缺纸");
        break;
    case TDL_PRINTER_EVENT_PAPER_IN:
        PR_NOTICE("纸张已装入");
        break;
    case TDL_PRINTER_EVENT_OVERHEATED:
        PR_WARN("打印头过热");
        break;
    default:
        break;
    }
}
```

> **注意**：DP48A 的 `get_status` 暂未实现（需要 UART 接收解析），状态回调对 DP48A 无效。

---

## 5. 接口速查

### TDL 层（`tdl_printer_manage.h`）

| 函数 | 说明 |
|---|---|
| `tdl_printer_find(name, &handle)` | 按名字查找已注册打印机 |
| `tdl_printer_open(handle, param)` | 打开打印机，可选状态监控 |
| `tdl_printer_close(handle)` | 关闭打印机，释放资源 |
| `tdl_printer_start(handle)` | 开始打印任务（MTP02 需要） |
| `tdl_printer_end(handle)` | 结束打印任务（MTP02 需要） |
| `tdl_printer_send(handle, data, len)` | 发送原始字节（ESC/POS 命令等） |
| `tdl_printer_send_text(handle, utf8)` | 发送 UTF-8 文字（TDL 自动处理编码） |
| `tdl_printer_send_bitmap(handle, x, w, h, data)` | 发送单色位图（TDL 自动生成协议命令） |
| `tdl_printer_paper_feed(handle, lines)` | 进纸 n 点行 |
| `tdl_printer_get_dev_info(handle, &info)` | 获取打印机参数 |

### TDD 注册（`tdd_printer_dp48.h`）

| 函数 | 说明 |
|---|---|
| `tdd_printer_dp48_register(name, cfg)` | 注册 DP48A 驱动 |

---

## 6. 常用 ESC/POS 命令参考

| 功能 | 命令字节 |
|---|---|
| 初始化（复位） | `1B 40` |
| 左对齐 | `1B 61 00` |
| 居中对齐 | `1B 61 01` |
| 右对齐 | `1B 61 02` |
| 加粗开 / 关 | `1B 45 01` / `1B 45 00` |
| 下划线开 / 关 | `1B 2D 01` / `1B 2D 00` |
| 反白开 / 关 | `1D 42 01` / `1D 42 00` |
| 字号：双高 | `1D 21 01` |
| 字号：双宽 | `1D 21 10` |
| 字号：双高双宽 | `1D 21 11` |
| 字号：正常 | `1D 21 00` |
| 进纸 n 行 | `1B 64 n` |
| 进纸 n 点 | `1B 4A n` |
| 全切纸 | `1D 56 00` |
| 半切纸 | `1D 56 01` |
| 打印位图 | `1D 76 30 00 xL xH yL yH [data]` |
| 设置水平位置 | `1B 24 nL nH` |
| 查询打印机状态 | `10 04 01` |
| 查询缺纸状态 | `1D 72 01` |

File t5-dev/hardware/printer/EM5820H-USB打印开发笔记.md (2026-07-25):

# EM5820H USB 打印 — 开发笔记（2026-07 落地版）

> 赛博财神庙单板方案：T5AI-Board 直接通过板载 USB-A 口驱动 EM5820H 热敏打印机。
> 抽签出结果后自动打印签文小票。本文是全部实现细节与踩坑记录。

## 1. 硬件与打印机身份

| 项 | 值 |
|---|---|
| 打印机 | 优库 EM5820H（58mm 面板式热敏，外置 5V 供电） |
| 自报身份 | `MANUFACTURER:;COMMAND SET:TSC/ESC/POS;MODEL:58A;COMMENT:dw-printer`（IEEE1284 GET_DEVICE_ID） |
| USB | VID=0x1d81 PID=0x5721，接口 Class:0x07 Subclass:0x01 Protocol:0x02（标准 USB 打印机类，双向） |
| 指令集 | ESC/POS（实测有效）；TSC 也支持但未使用 |
| 供电 | 5V 工作 1.3~1.6A、峰值 2.1A —— 电源必须 ≥2A |
| 连接 | 打印机 MINI-USB-B ↔ 板载 USB-A 口 |

文档：`hardware/printer/`（DW 版规格书 + 用户手册 PDF + 手册文本版）。

## 2. USB Host 使能配方（T5AI-Board）

```c
/* GPIO28 = 板载 USB VBUS 开关（来源：tkl_mftest.c 工厂测试） */
TUYA_GPIO_BASE_CFG_T cfg = {.mode=TUYA_GPIO_PULLUP, .direct=TUYA_GPIO_OUTPUT, .level=TUYA_GPIO_LEVEL_HIGH};
tkl_gpio_init(TUYA_GPIO_NUM_28, &cfg);
tkl_gpio_write(TUYA_GPIO_NUM_28, TUYA_GPIO_LEVEL_HIGH);
bk_usb_open(0);   /* 0 = USB_HOST_MODE，平台默认已编译 CONFIG_USB_HOST=y */
```

## 3. 自研 CherryUSB 打印机类驱动

平台自带的 `usbh_printer.c` 不可用（未编译进 CMake、协议匹配要求 0x00、代码有 bug）。
自研驱动按 `usbh_ch34x.c` 模式实现，**仅按 Class=0x07 匹配**：

| 文件 | 作用 |
|---|---|
| `platform/T5AI/t5_os/ap/components/bk_usb/bk_usbh_printer/bk_usbh_printer.{c,h}` | 驱动本体：连接时激活 bulk in/out 管道、dump IEEE1284 身份；`bk_usbh_printer_is_connected()` / `bk_usbh_printer_write()` |
| `.../bk_usb/CherryUSB/driver/usb_driver.c` | `bk_usb_init_all_device_driver_sw()` 里调用 `bk_usbh_printer_class_register()`（Beken 是**运行时注册**类驱动表，不是链接段） |
| `.../bk_usb/CMakeLists.txt` | CONFIG_USB_HOST 下加入 inc + src |
| `.../CherryUSB/core/usbh_core.c` | 加了 bk_printf 枚举探针（Class/Protocol dump），保留便于日后排查 |
| `platform/.../tkl_mftest.c` | `tkl_mftest_usb_info()` 里加了 VID/PID 打印 |

要点：
- CherryUSB 原生日志是 BK_LOGD/BK_LOGV，默认被过滤 —— 排查必须用 `bk_printf`
- DMA 缓冲区需 `USB_NOCACHE_RAM_SECTION USB_MEM_ALIGNX`
- 写入走 `usbh_bulk_urb_fill` + `usbh_submit_urb`，按 ≤512B 分块

## 4. 应用层（apps/cyber_fortune）

| 文件 | 作用 |
|---|---|
| `src/fortune_printer.c` + `include/fortune_printer.h` | 打印工作线程（信号量队列，UI 零阻塞）+ ESC/POS 小票排版 |
| `src/fortune_gbk_map.c` | 自动生成的 Unicode→GBK 表（1169 字，二分查找），覆盖签谱全部汉字 |
| `t5-dev/tools/gen_gbk_map.py` | **签谱数据（qianpu_data.c）更新后必须重跑**，重新生成映射表 |
| `src/fortune_ui.c` | `draw_timer_cb()` 出结果时调 `fortune_printer_print_lot(lot)` |
| `src/tuya_main.c` | 启动时 `usb_host_probe_start()` + `fortune_printer_init()` |

小票版式（58mm = 32 ASCII 列 / 16 汉字列）：
居中双倍"赛博财神庙" → 第 X 签 · 等级 → 倍高签题 → 主题 → 分隔线 → 签诗 → 分隔线 → 左对齐白话解签 → 页脚 → 5×LF 走纸过撕纸位。

常用 ESC/POS：`1B 40` 初始化；`1B 61 n` 对齐；`1D 21 n` 字号（0x11=倍宽倍高）；中文直接发 GBK 双字节。

## 5. 踩坑记录（按杀伤力排序）

1. **热敏纸装反 → 走纸正常但完全空白**。热敏纸只有一面有涂层；指甲快速划纸，发黑面为热敏面，须朝向打印头。验证手段：开机长按 FEED 打自检页（不经过 USB，纯硬件自检）。
2. **CherryUSB 枚举日志不可见**：默认日志级别过滤掉 DBG/VBS，看起来像"没枚举"，实际枚举成功。加 `bk_printf` 探针确认。
3. **平台 stock usbh_printer.c 不可用**：没进 CMake、匹配条件错、`intf+1` 下标 bug。
4. **Beken 类驱动是运行时注册**：往 `usbh_class_info_table[]` 注册，不是标准 CherryUSB 的链接段方式；新驱动必须在 `bk_usb_init_all_device_driver_sw()` 挂上。
5. GET_PORT_STATUS 控制请求此机型返回 -116（不支持），GET_DEVICE_ID 正常 —— 不要依赖 port status 判断缺纸。
6. 双模打印机（TSC/ESC/POS）如疑似模式不对：ESC/POS 发 `1D 28 41 02 00 00 02`（测试页）、TSC 发 `SELFTEST\r\n`，哪个出纸就在哪个模式。本机 ESC/POS 直接可用，无需切换。

## 6. 验证记录

- 枚举 → 类驱动加载 → bulk-out 全链路日志验证通过（字节数 ACK 一致）
- 中文 GBK、居中、倍大字号实打验证通过
- 抽签联动：`[fortune-printer] lot 30 ticket: 426 bytes built, 426 sent`，实体小票输出正常

## 7. 日常迭代工作流

```bash
cd t5-dev
bash cf_build.sh     # 编译
bash cf_flash.sh     # 烧录（~61s，自动重启）
bash cf_monitor.sh   # 串口监视（460800，日志 tee 到 /tmp/cf_mon.log）
```

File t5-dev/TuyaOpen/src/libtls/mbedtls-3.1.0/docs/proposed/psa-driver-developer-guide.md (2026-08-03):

PSA Cryptoprocessor driver developer's guide
============================================

**This is a specification of work in progress. The implementation is not yet merged into Mbed TLS.**

This document describes how to write drivers of cryptoprocessors such as accelerators and secure elements for the PSA cryptography subsystem of Mbed TLS.

This document focuses on behavior that is specific to Mbed TLS. For a reference of the interface between Mbed TLS and drivers, refer to the [PSA Cryptoprocessor Driver Interface specification](psa-driver-interface.html).

The interface is not fully implemented in Mbed TLS yet and is disabled by default. You can enable the experimental work in progress by setting `MBEDTLS_PSA_CRYPTO_DRIVERS` in the compile-time configuration. Please note that the interface may still change: until further notice, we do not guarantee backward compatibility with existing driver code when `MBEDTLS_PSA_CRYPTO_DRIVERS` is enabled.

## Introduction

### Purpose

The PSA cryptography driver interface provides a way to build Mbed TLS with additional code that implements certain cryptographic primitives. This is primarily intended to support platform-specific hardware.

There are two types of drivers:

* **Transparent** drivers implement cryptographic operations on keys that are provided in cleartext at the beginning of each operation. They are typically used for hardware **accelerators**. When a transparent driver is available for a particular combination of parameters (cryptographic algorithm, key type and size, etc.), it is used instead of the default software implementation. Transparent drivers can also be pure software implementations that are distributed as plug-ins to a PSA Crypto implementation.
* **Opaque** drivers implement cryptographic operations on keys that can only be used inside a protected environment such as a **secure element**, a hardware security module, a smartcard, a secure enclave, etc. An opaque driver is invoked for the specific key location that the driver is registered for: the dispatch is based on the key's lifetime.

### Deliverables for a driver

To write a driver, you need to implement some functions with C linkage, and to declare these functions in a **driver description file**. The driver description file declares which functions the driver implements and what cryptographic mechanisms they support. Depending on the driver type, you may also need to define some C types and macros in a header file.

The concrete syntax for a driver description file is JSON. The structure of this JSON file is specified in the section [“Driver description syntax”](psa-driver-interface.html#driver-description-syntax) of the PSA cryptography driver interface specification.

A driver therefore consists of:

* A driver description file (in JSON format).
* C header files defining the types required by the driver description. The names of these header files is declared in the driver description file.
* An object file compiled for the target platform defining the functions required by the driver description. Implementations may allow drivers to be provided as source files and compiled with the core instead of being pre-compiled.

## Driver C interfaces

Mbed TLS calls driver entry points [as specified in the PSA Cryptography Driver Interface specification](psa-driver-interface.html#driver-entry-points) except as otherwise indicated in this section.

## Building and testing your driver

<!-- TODO -->

## Dependencies on the Mbed TLS configuration

<!-- TODO -->

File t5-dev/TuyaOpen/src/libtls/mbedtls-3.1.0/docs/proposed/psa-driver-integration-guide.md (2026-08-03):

Building Mbed TLS with PSA cryptoprocessor drivers
==================================================

**This is a specification of work in progress. The implementation is not yet merged into Mbed TLS.**

This document describes how to build Mbed TLS with additional cryptoprocessor drivers that follow the PSA cryptoprocessor driver interface.

The interface is not fully implemented in Mbed TLS yet and is disabled by default. You can enable the experimental work in progress by setting `MBEDTLS_PSA_CRYPTO_DRIVERS` in the compile-time configuration. Please note that the interface may still change: until further notice, we do not guarantee backward compatibility with existing driver code when `MBEDTLS_PSA_CRYPTO_DRIVERS` is enabled.

## Introduction

The PSA cryptography driver interface provides a way to build Mbed TLS with additional code that implements certain cryptographic primitives. This is primarily intended to support platform-specific hardware.

Note that such drivers are only available through the PSA cryptography API (crypto functions beginning with `psa_`, and X.509 and TLS interfaces that reference PSA types).

Concretely speaking, a driver consists of one or more **driver description files** in JSON format and some code to include in the build. The driver code can either be provided in binary form as additional object file to link, or in source form.

## How to build Mbed TLS with drivers

To build Mbed TLS with drivers:

1. Activate `MBEDTLS_PSA_CRYPTO_DRIVERS` in the library configuration.

    ```
    cd /path/to/mbedtls
    scripts/config.py set MBEDTLS_PSA_CRYPTO_DRIVERS
    ```

2. Pass the driver description files through the Make variable `PSA_DRIVERS` when building the library.

    ```
    cd /path/to/mbedtls
    make PSA_DRIVERS="/path/to/acme/driver.json /path/to/nadir/driver.json" lib
    ```

3. Link your application with the implementation of the driver functions.

    ```
    cd /path/to/application
    ld myapp.o -L/path/to/acme -lacmedriver -L/path/to/nadir -lnadirdriver -L/path/to/mbedtls -lmbedcrypto
    ```

<!-- TODO: what if the driver is provided as C source code? -->

<!-- TODO: what about additional include files? -->

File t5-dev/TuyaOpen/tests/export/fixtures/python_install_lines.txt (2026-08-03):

Downloading cpython-3.12.13-linux-x86_64-gnu (25.6 MiB)
12.5 MiB / 25.6 MiB

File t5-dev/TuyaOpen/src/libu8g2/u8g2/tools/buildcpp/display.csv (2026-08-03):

# 1. device name
# 2. pinset
# 3. constructor name w/o prefix
u8x8_d_ssd1306_128x64_noname | 4WSWSPI | SSD1306_128X64_4W_SW_SPI
u8x8_d_ssd1306_128x64_noname | 4WHWSPI | SSD1306_128X64_4W_HW_SPI
u8x8_d_ssd1306_128x64_noname | 3WSWSPI | SSD1306_128X64_3W_SW_SPI
u8x8_d_ssd1306_128x64_noname | SSDSWI2C | SSD1306_128X64_SW_I2C
u8x8_d_ssd1306_128x64_noname | 6800 | SSD1306_128X64_6800
u8x8_d_ssd1306_128x64_noname | 8080 | SSD1306_128X64_8080

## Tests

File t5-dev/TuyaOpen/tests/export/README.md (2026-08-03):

# Export script tests

Tests for `export.sh`, `export.ps1`, and the IDE progress protocol.

## Run all

```bash
bash tests/export/run_all.sh
```

On Windows (Git Bash / WSL), the same command works. PowerShell progress tests run when `pwsh` or `powershell` is available.

## Layout

| File | Purpose |
|---|---|
| `test_export.sh` | Integration and unit tests (migrated from `tools/test_export.sh`) |
| `test_progress.sh` | POSIX progress-line parser fixtures |
| `test_progress.ps1` | Windows progress-line parser fixtures |
| `test_uv_manifest_downloads.sh` | Download all uv mirrors (CN / Astral / GitHub) and verify SIZE + SHA256 |
| `fixtures/` | Sample uv/python/sync output lines |

## uv manifest download verification (network)

Downloads every artifact in `uv-manifest.env` and checks size and SHA256 against the manifest. Not included in `run_all.sh` (large downloads).

```bash
bash tests/export/test_uv_manifest_downloads.sh
bash tests/export/test_uv_manifest_downloads.sh --triple x86_64-unknown-linux-gnu
bash tests/export/test_uv_manifest_downloads.sh --source cn
```

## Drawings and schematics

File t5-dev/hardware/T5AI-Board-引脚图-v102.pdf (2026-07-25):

P10

# Tuya T5-AI Development Board

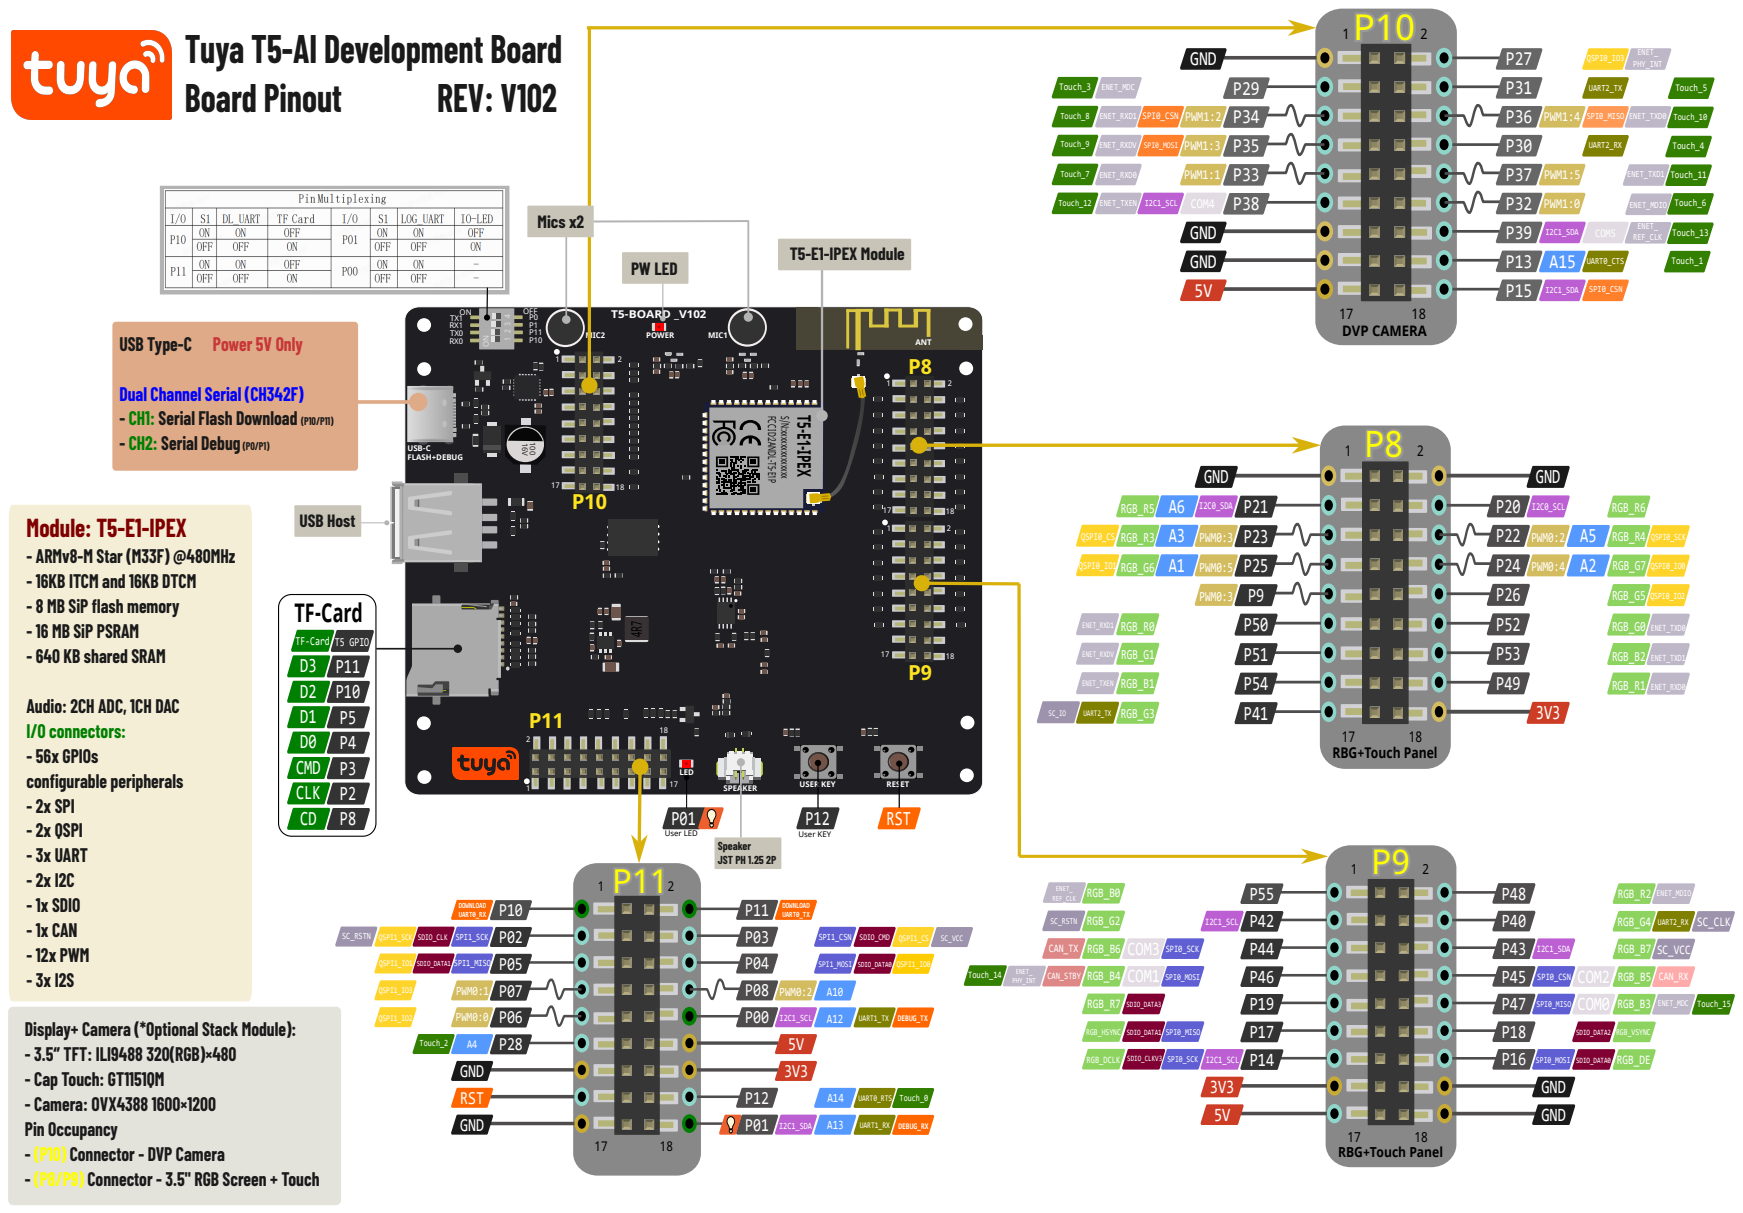
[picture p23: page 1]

USB Type-C Power 5V Only

Module: T5-E1-IPEX
- ARMv8-M Star (M33F) @480MHz
- 16KB ITCM and 16KB DTCM
- 8 MB SiP flash memory
- 16 MB SiP PSRAM
- 640 KB shared SRAM

Display+ Camera (*Optional Stack Module):
- 3.5‘’ TFT: ILI9488 320(RGB)×480
- Cap Touch: GT1151QM
- Camera: OVX4388 1600×1200
Pin Occupancy
- (P10) Connector - DVP Camera
- (P8/P9) Connector - 3.5" RGB Screen + Touch

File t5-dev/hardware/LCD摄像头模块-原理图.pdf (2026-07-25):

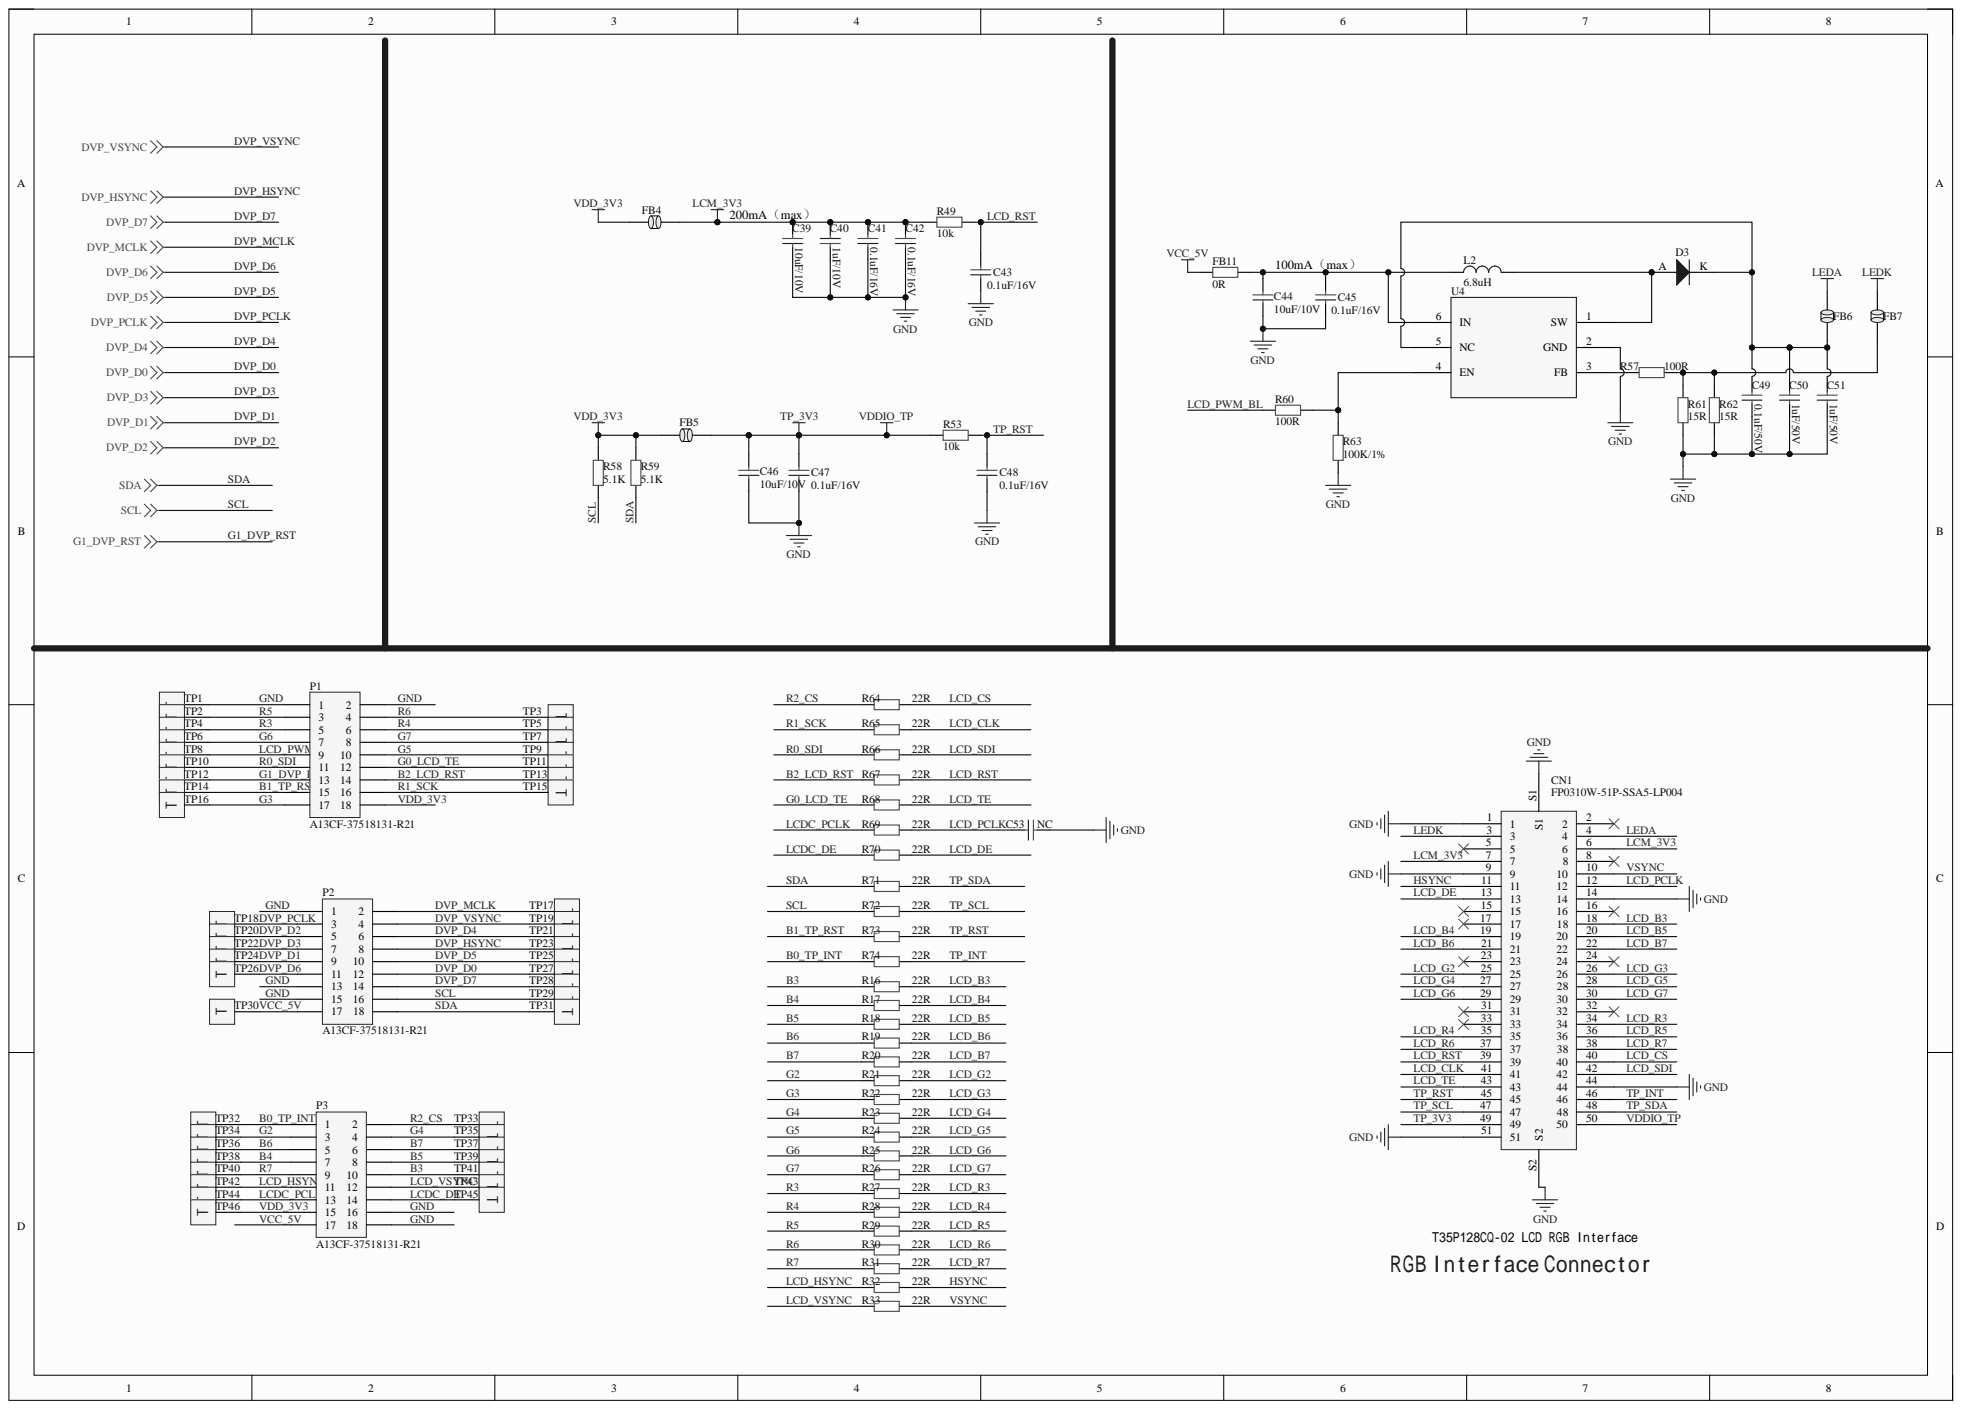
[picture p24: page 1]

TP2
TP4 R3 | R4 TP5 | T
TP6 G6 | G7 TP7 | T
TP8 LCD_PWM_BL | G5 TP9 | T
TP10 R0_SDI | G0_LCD_TE TP11 | T
TP12 G1_DVP_RST | B2_LCD_RST TP13 | T
TP14 B1_TP_RST | R1_SCK TP15 | T
TP16 G3

TP36 B6 | B7 TP37 | T
TP38 B4 | B5 TP39 | T
TP40 R7 | B3 TP41 | T
TP42 LCD_HSYNC | LCD_VSYNC TP43 | T
TP44 LCDC_PCLK | LCDC_DE TP45 | T
TP46

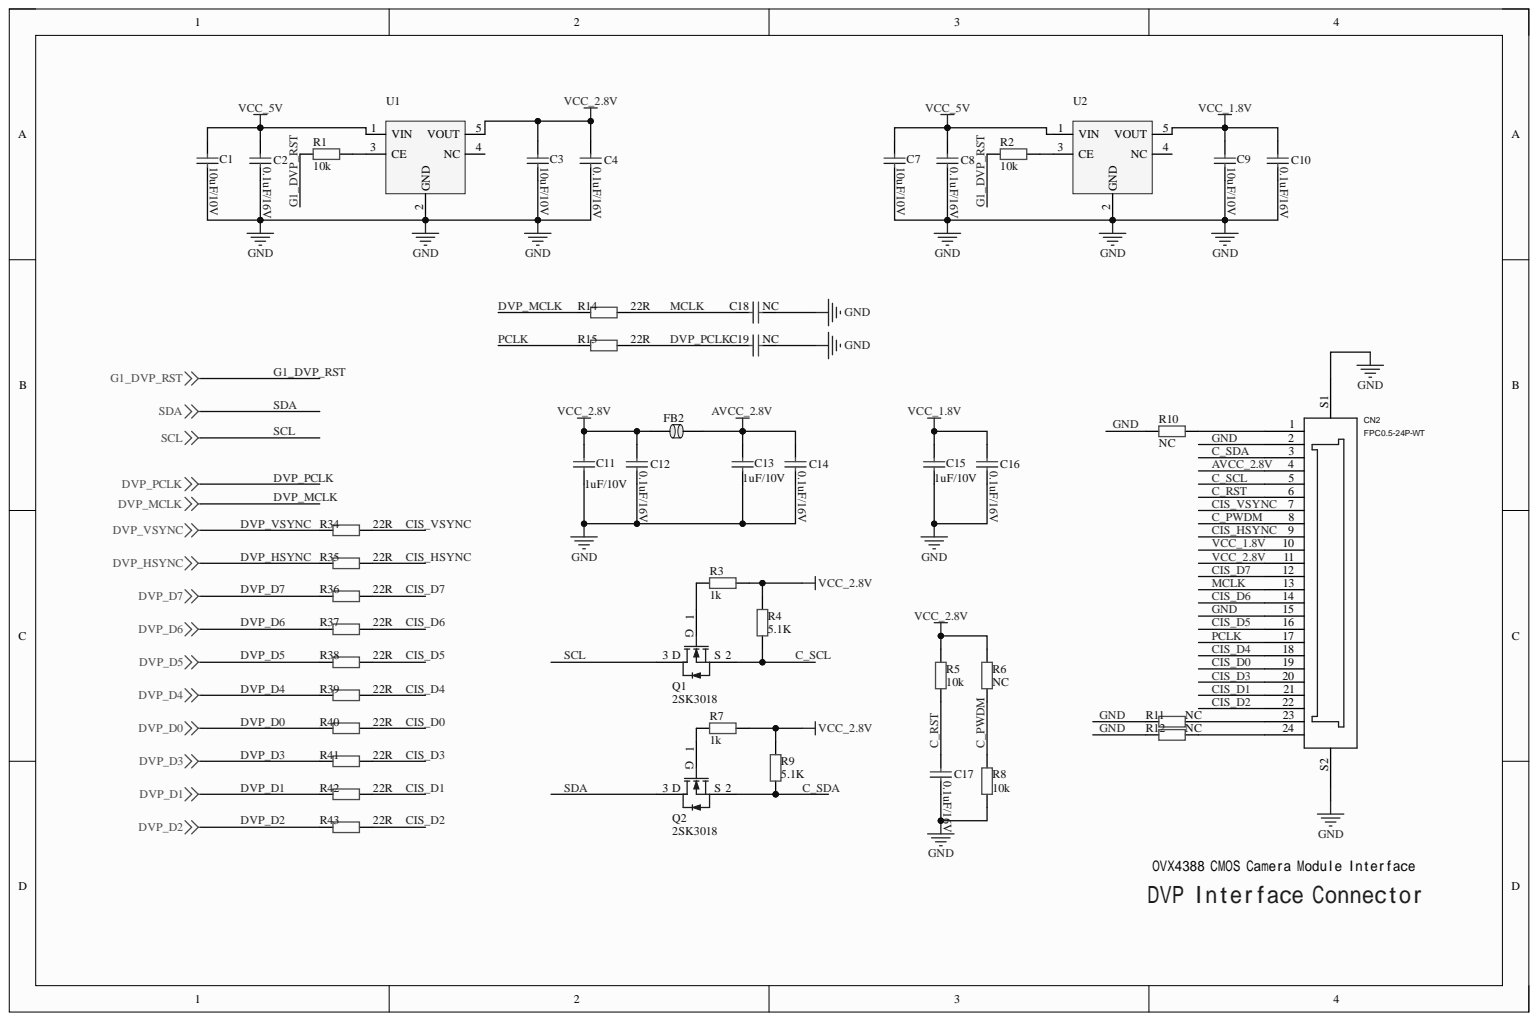
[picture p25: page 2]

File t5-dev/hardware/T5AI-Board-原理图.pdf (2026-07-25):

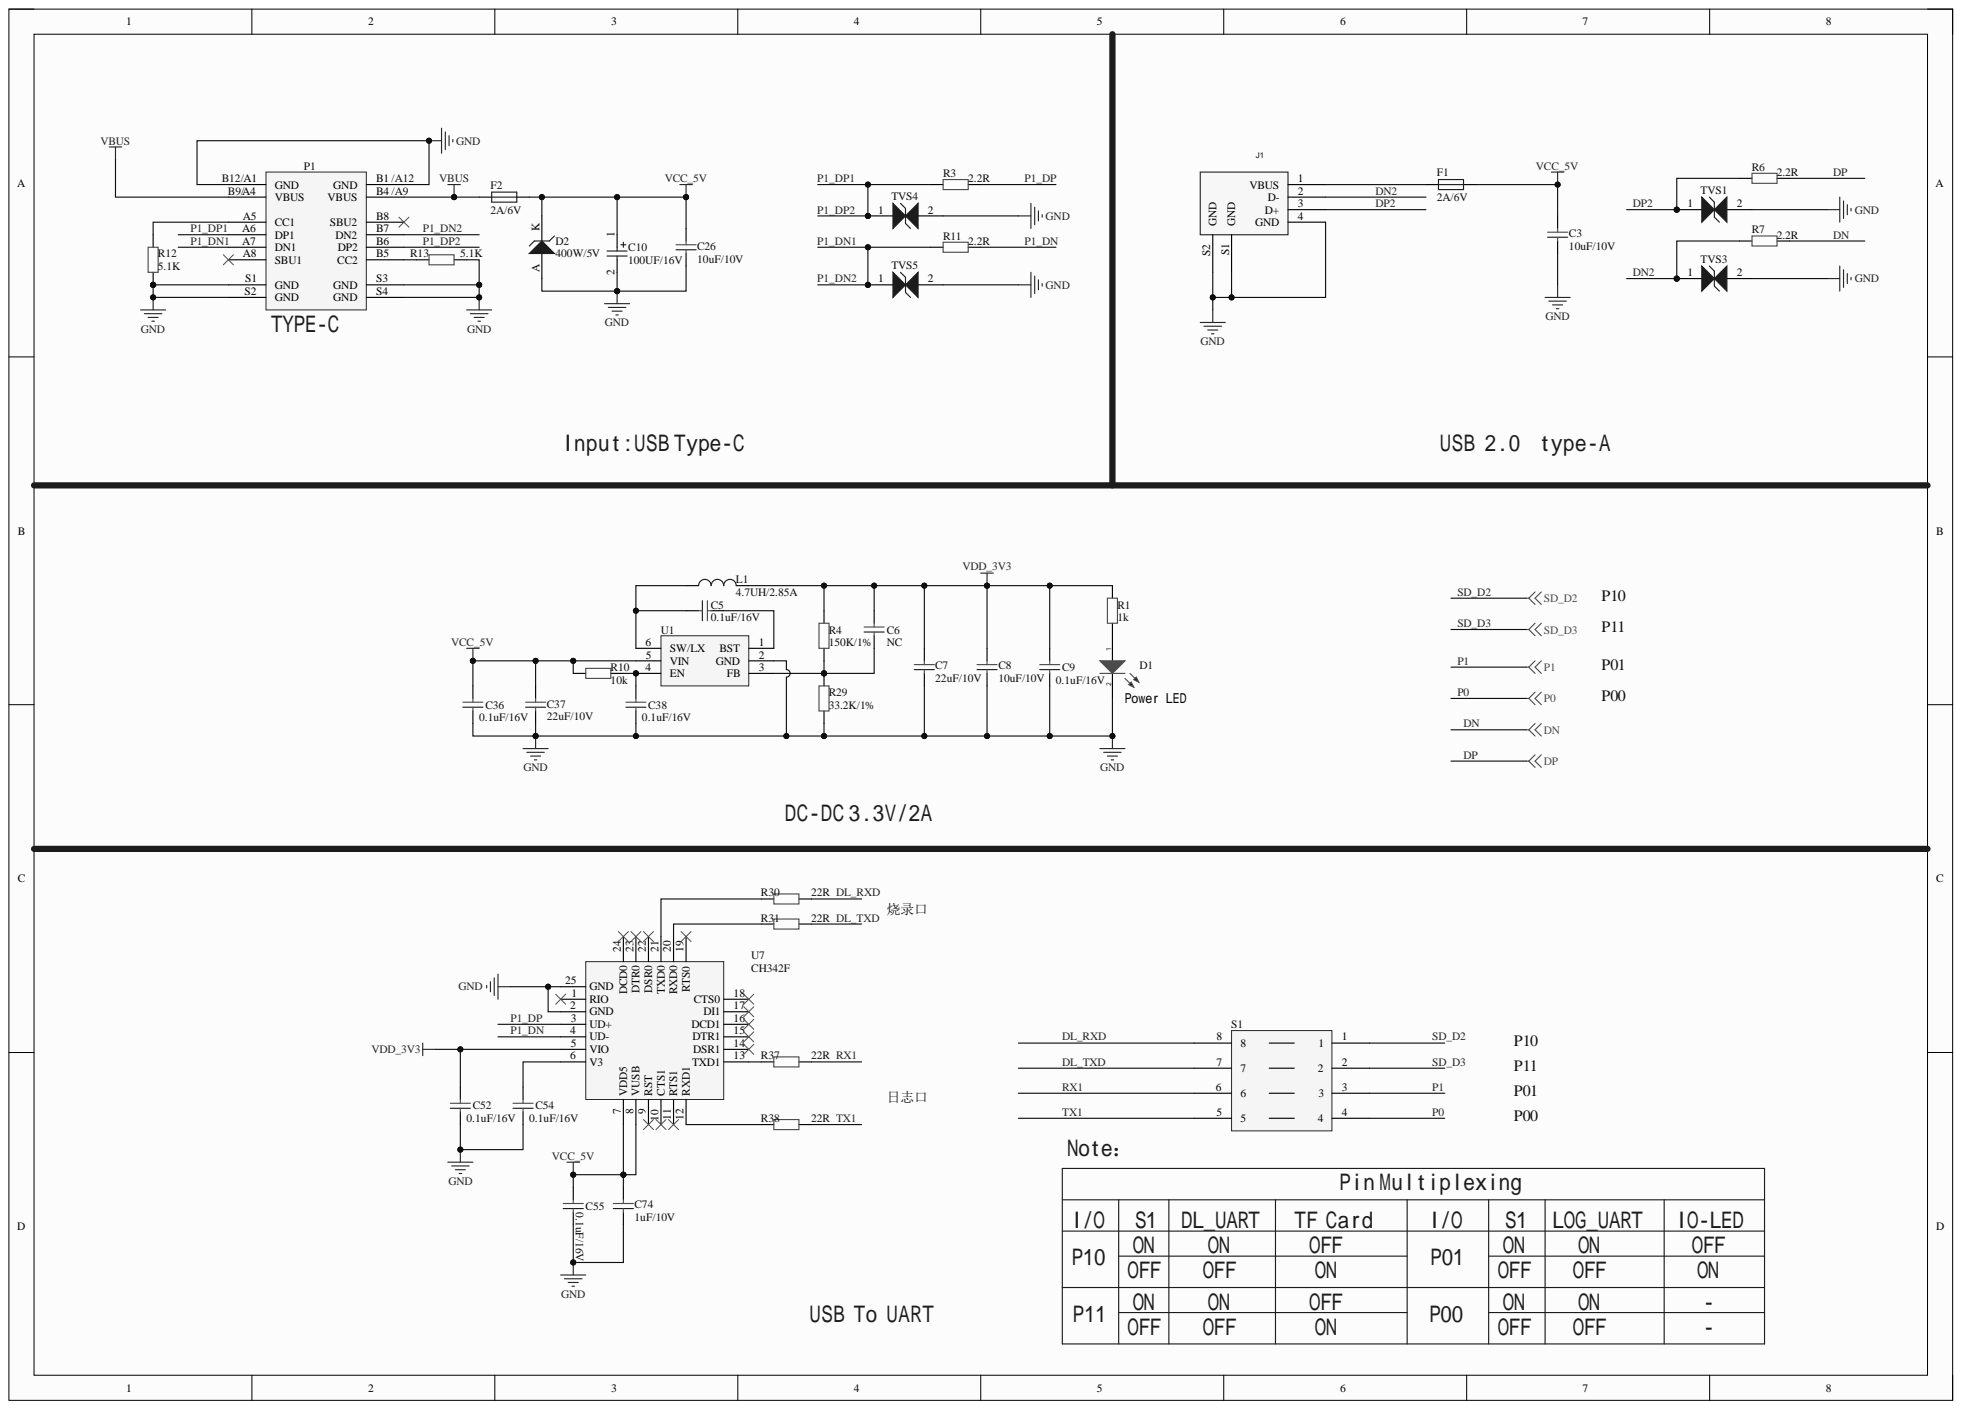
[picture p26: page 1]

I/ | DL_UA | | I/ | LOG_UA | IO-LE
P1 | | OF | P0 | | OF
OF | OF | | OF | OF
P1 | | OF | P0
OF | OF | OF | OF

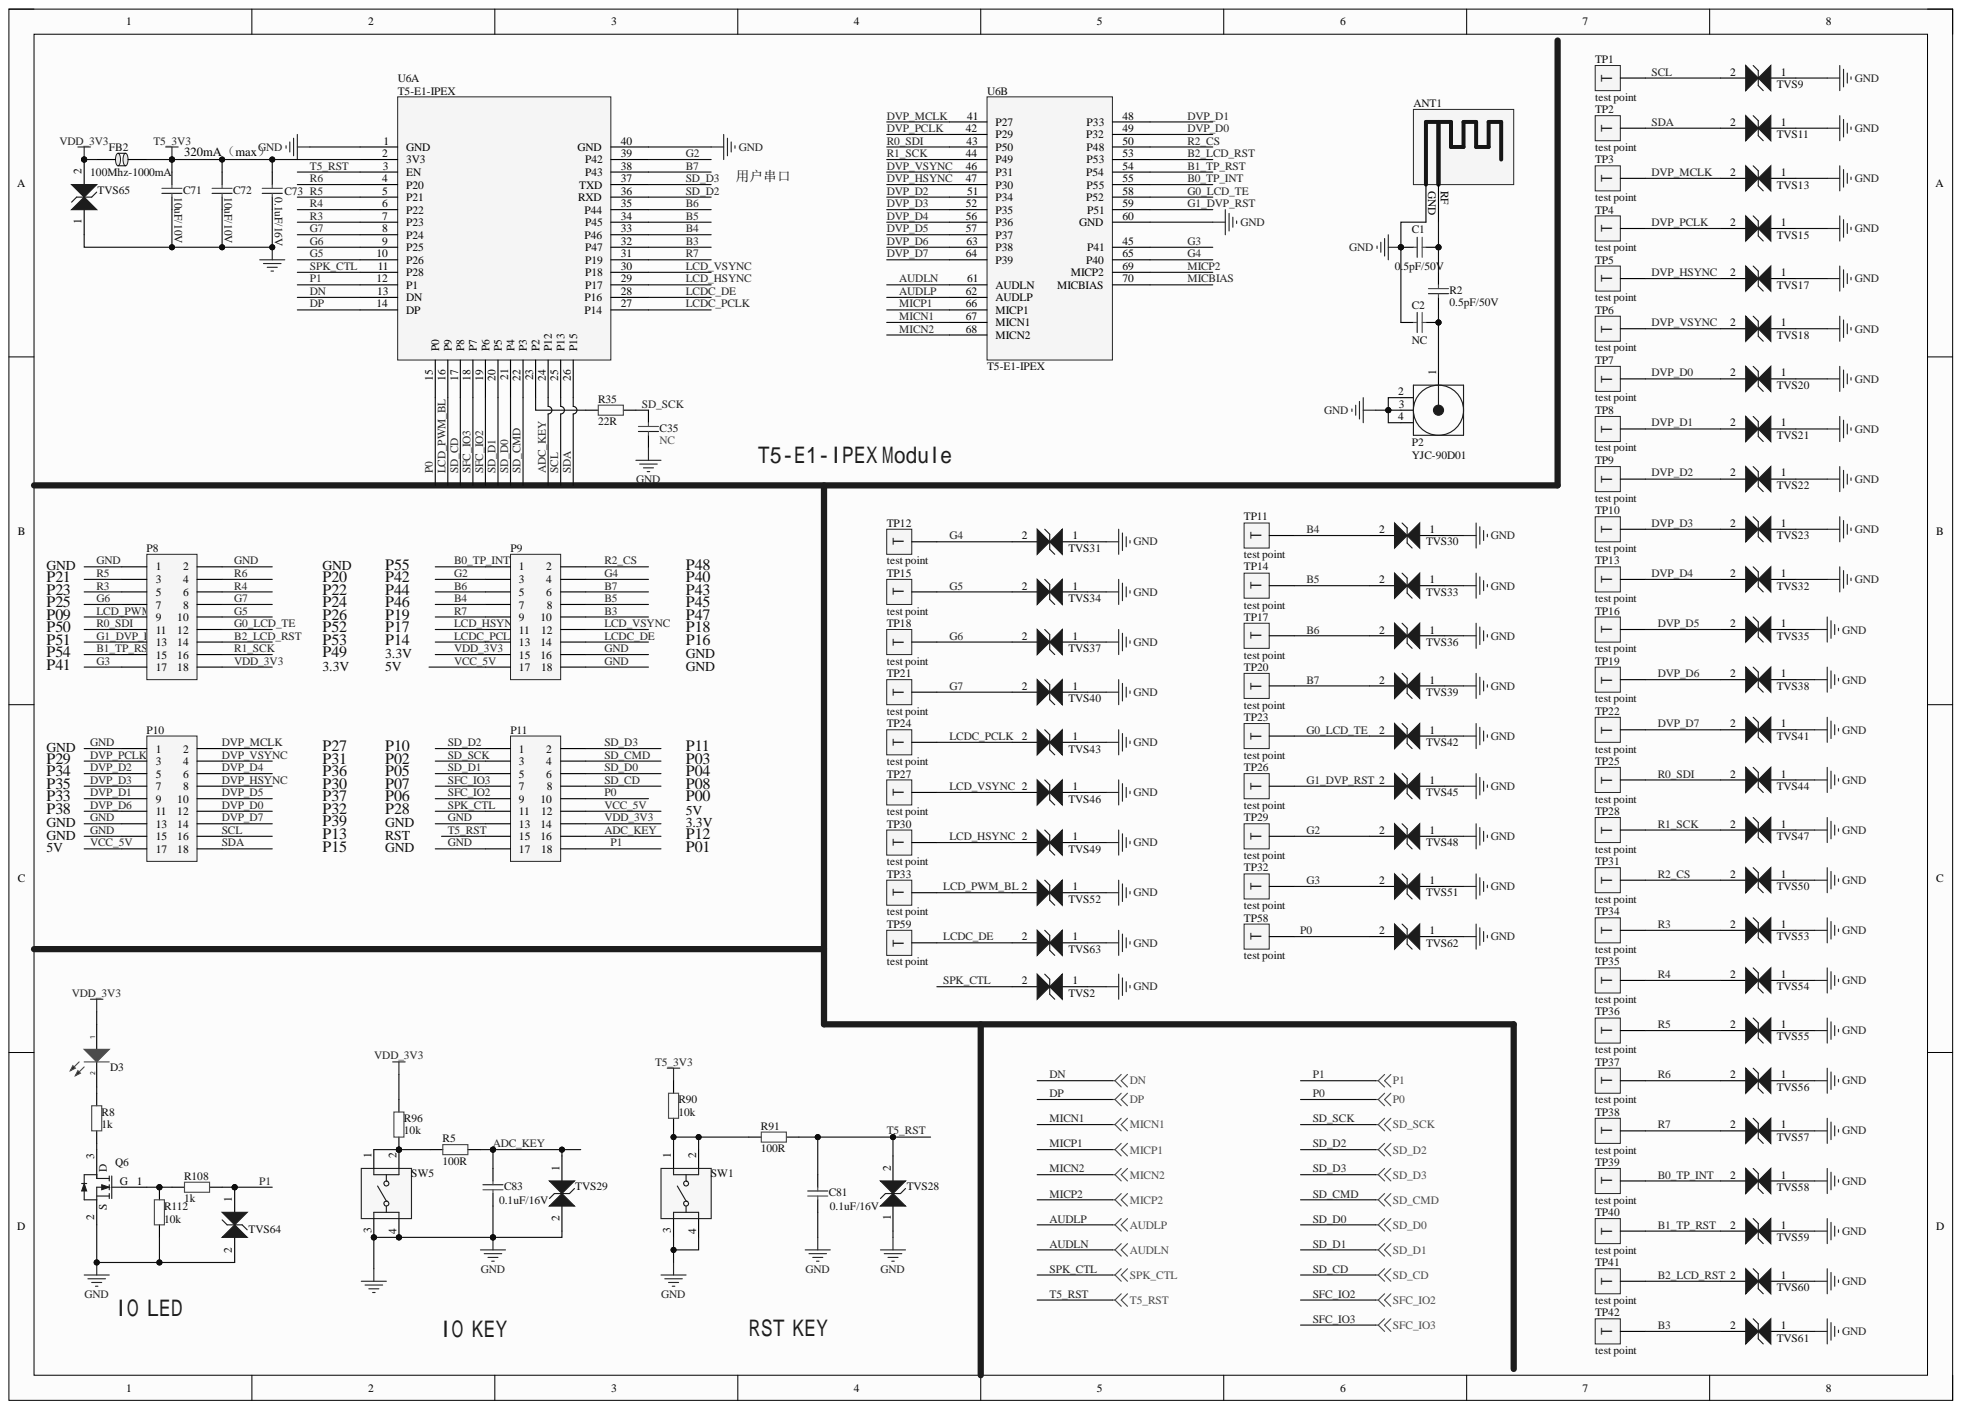
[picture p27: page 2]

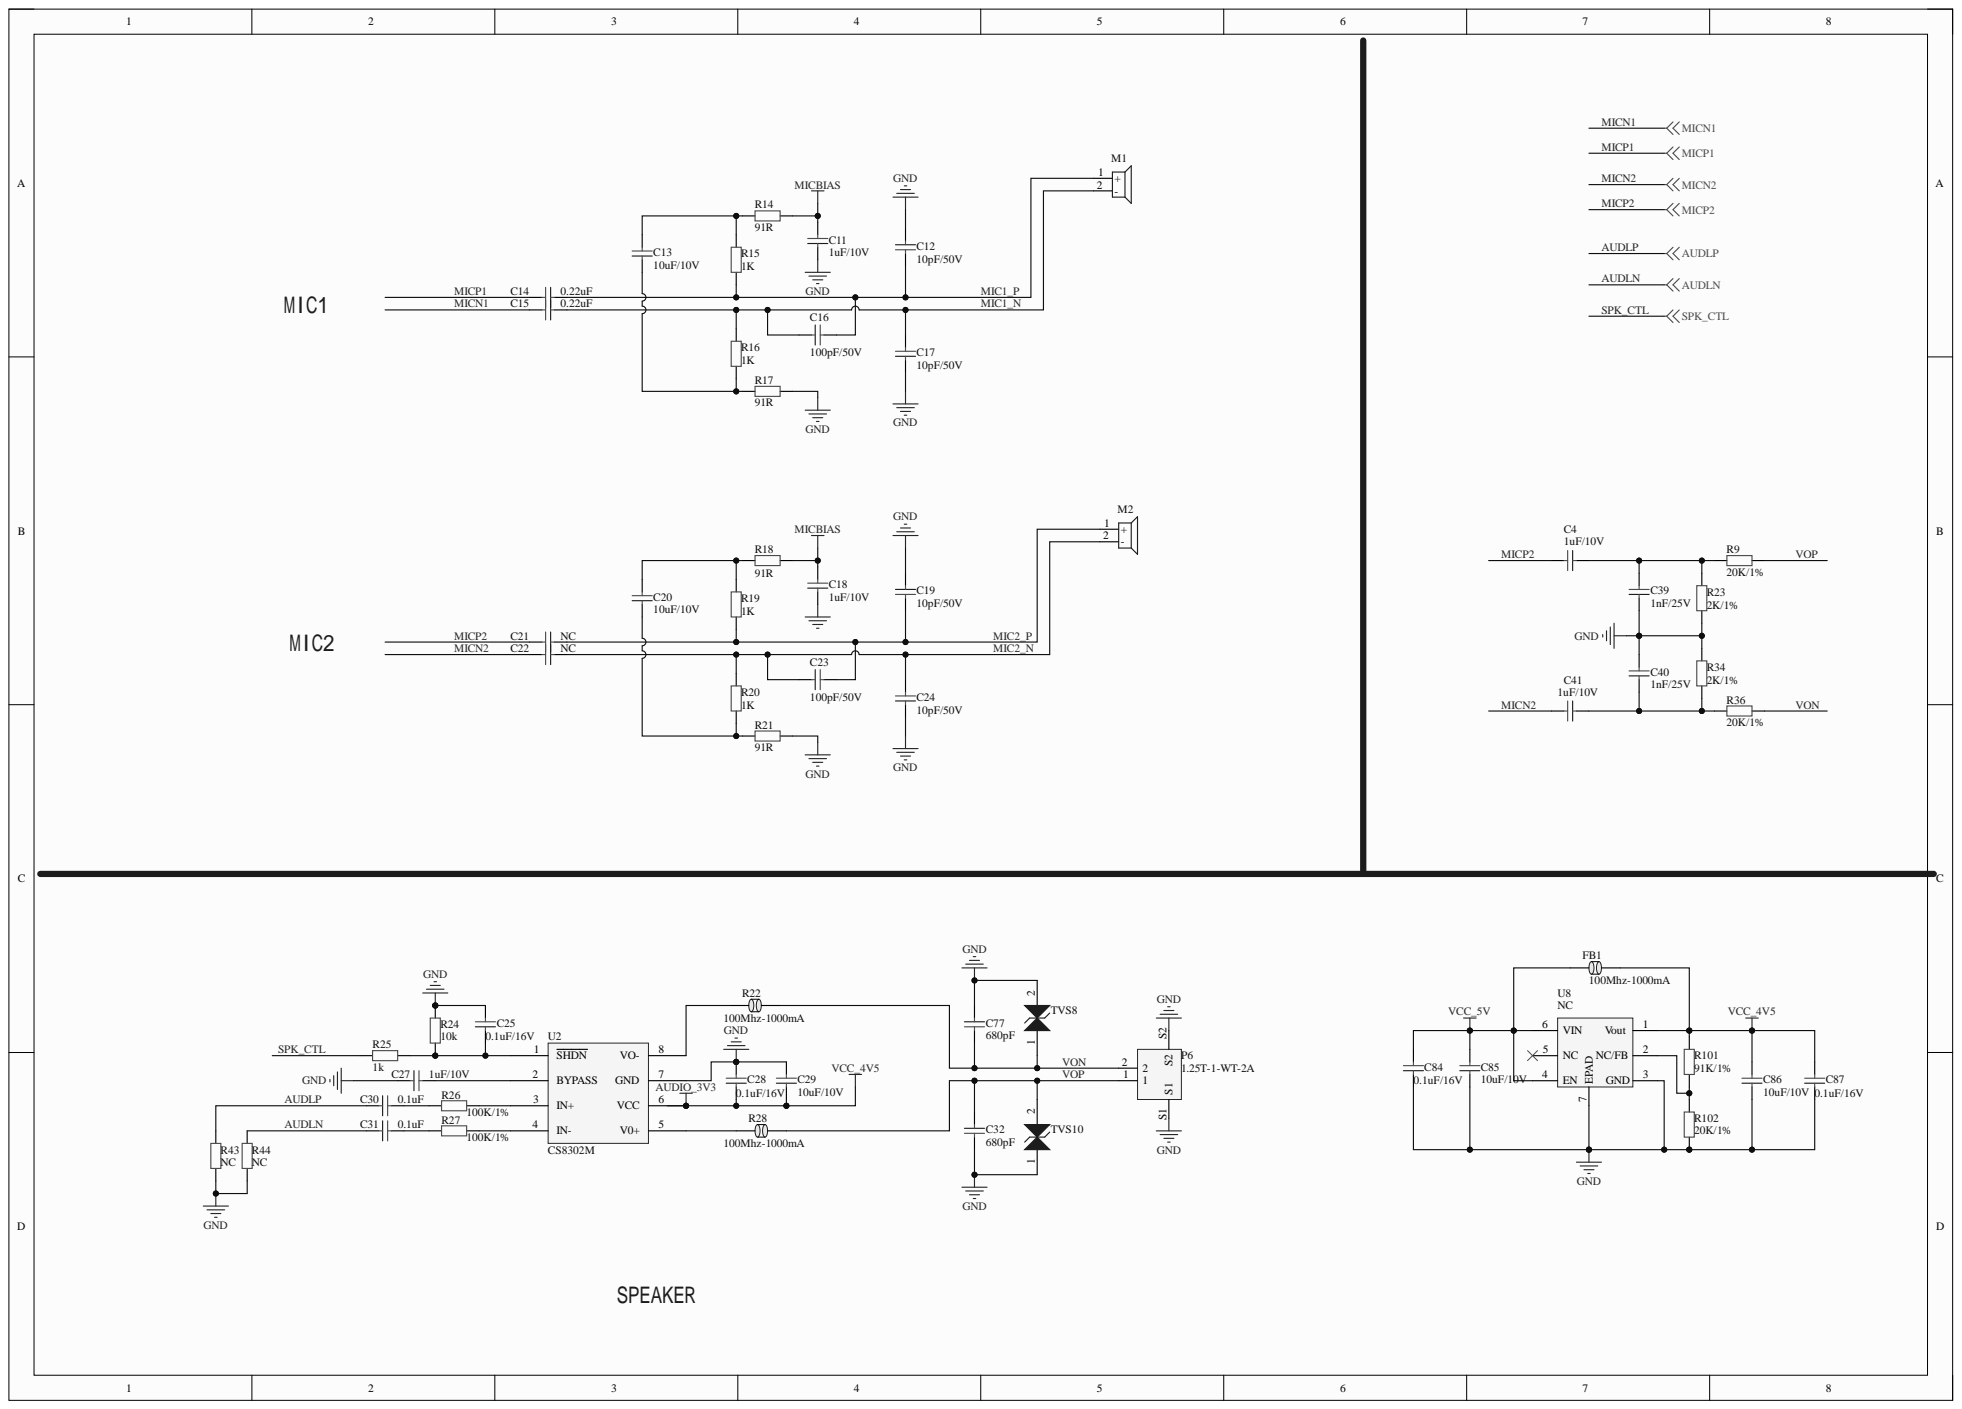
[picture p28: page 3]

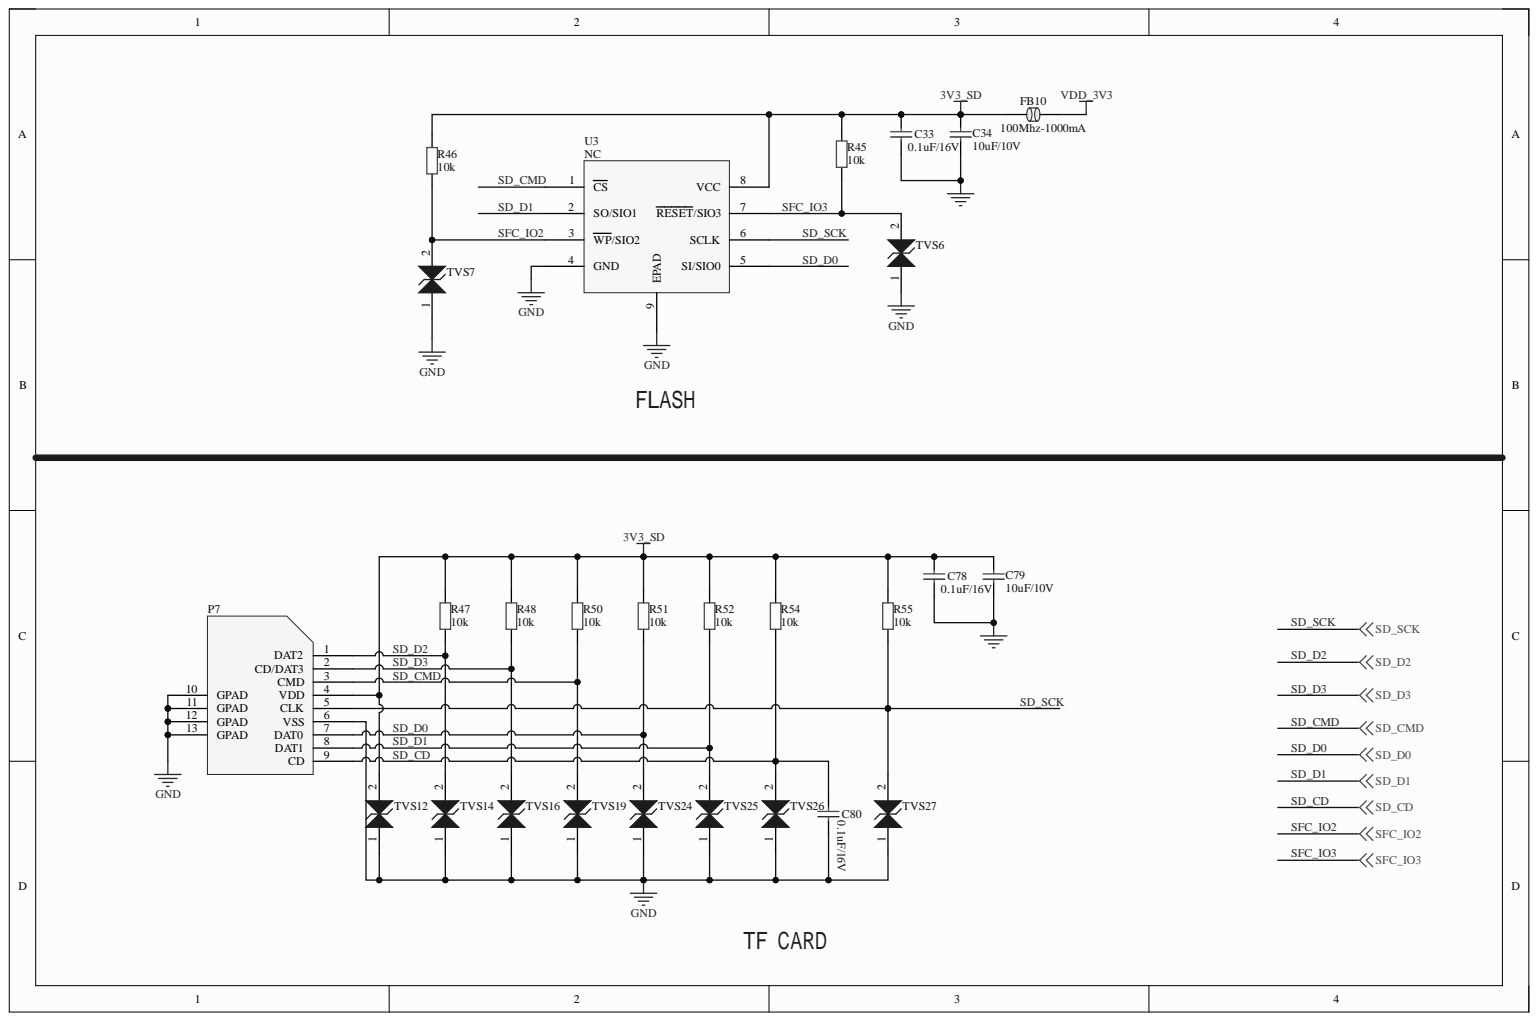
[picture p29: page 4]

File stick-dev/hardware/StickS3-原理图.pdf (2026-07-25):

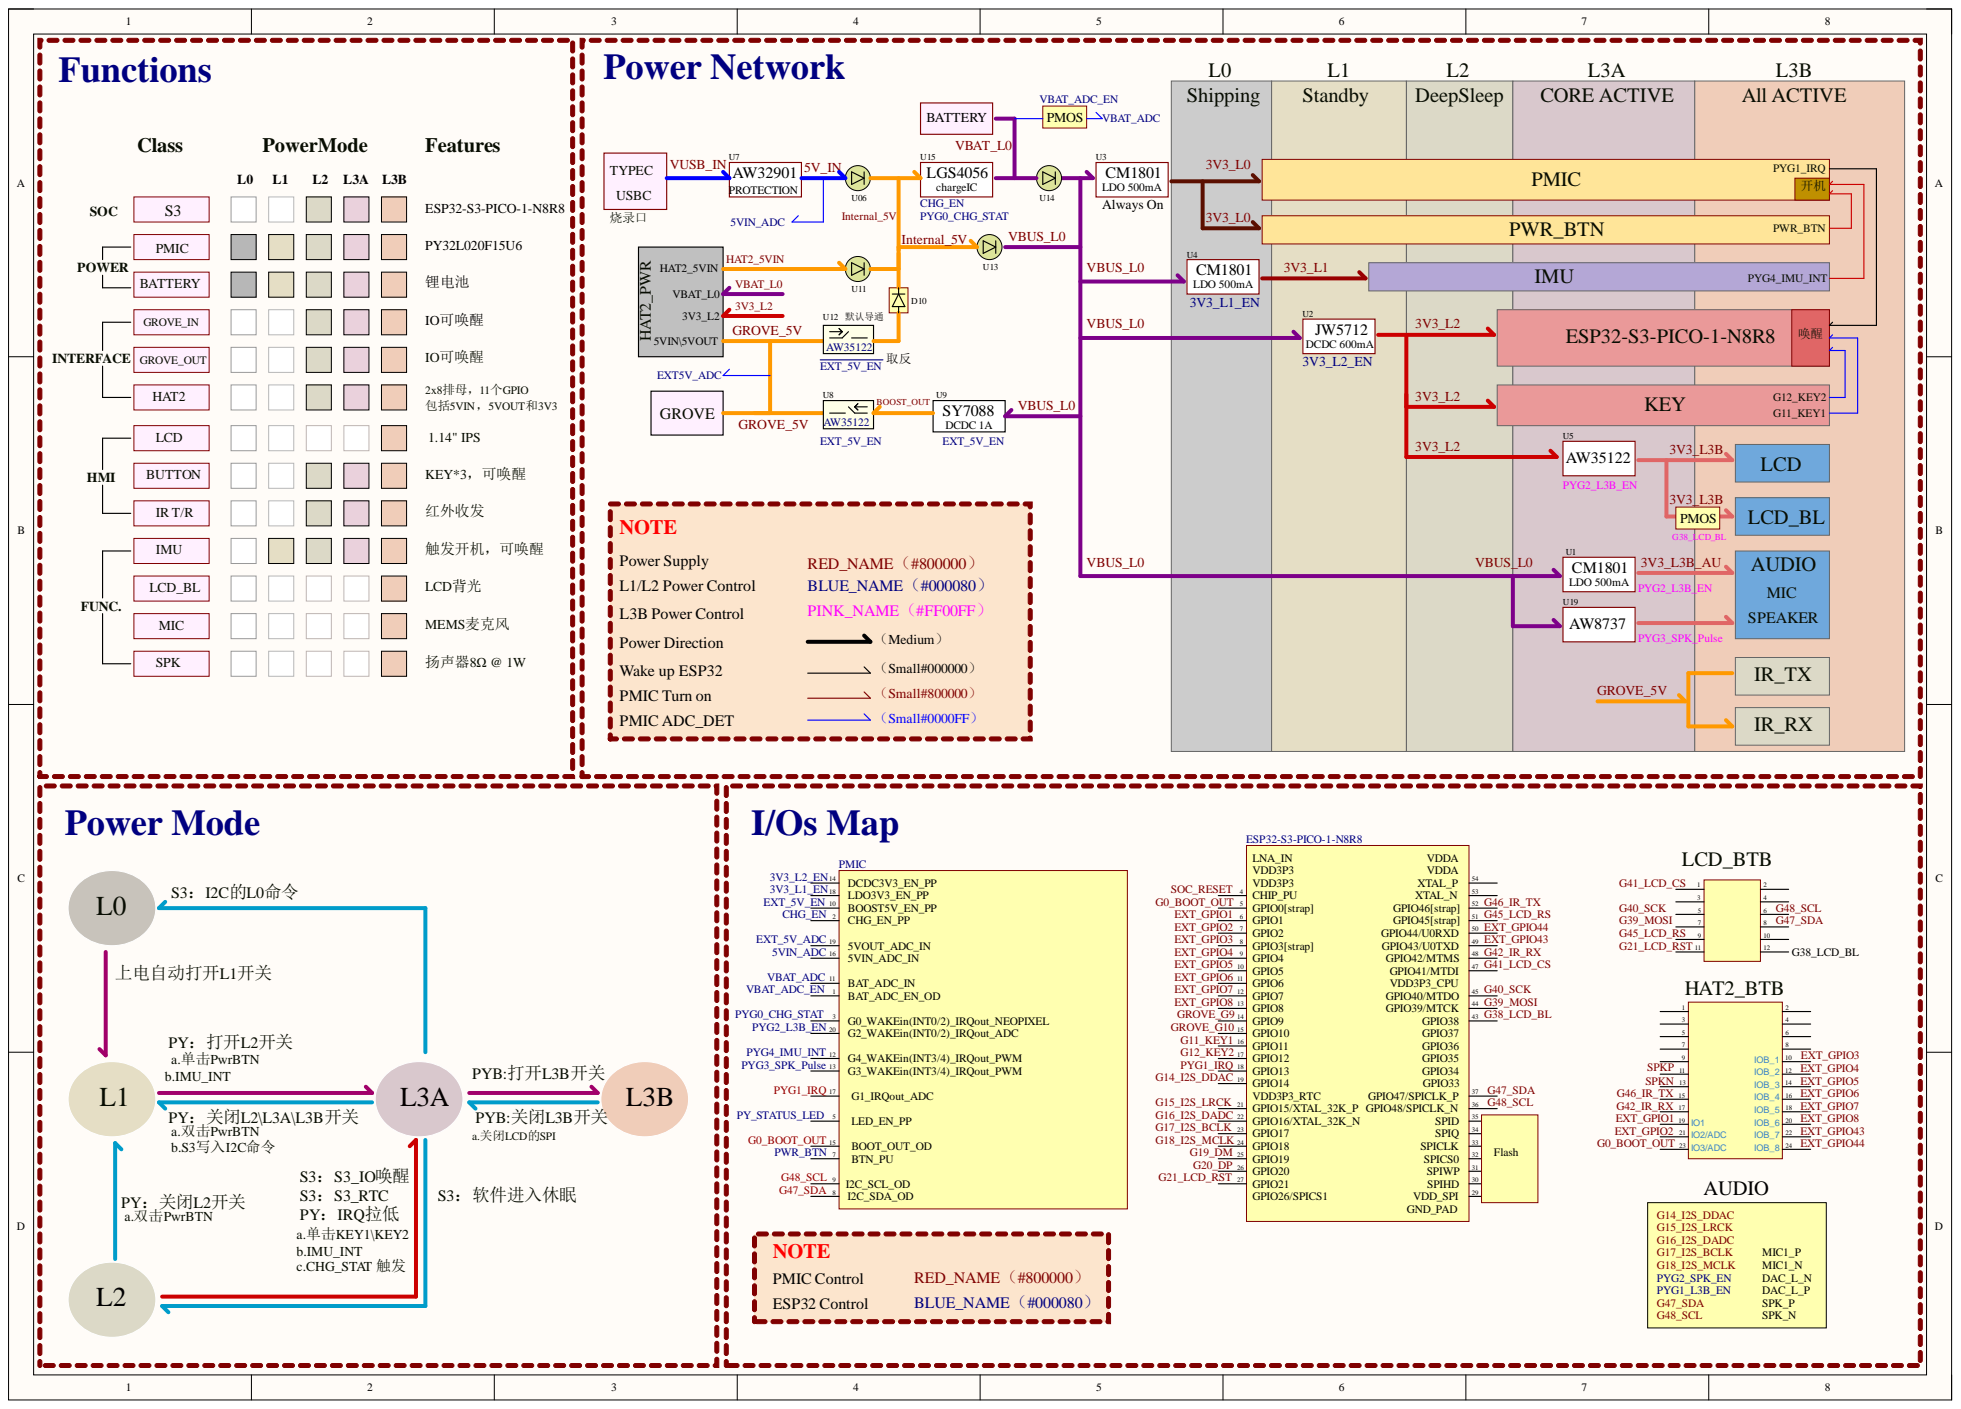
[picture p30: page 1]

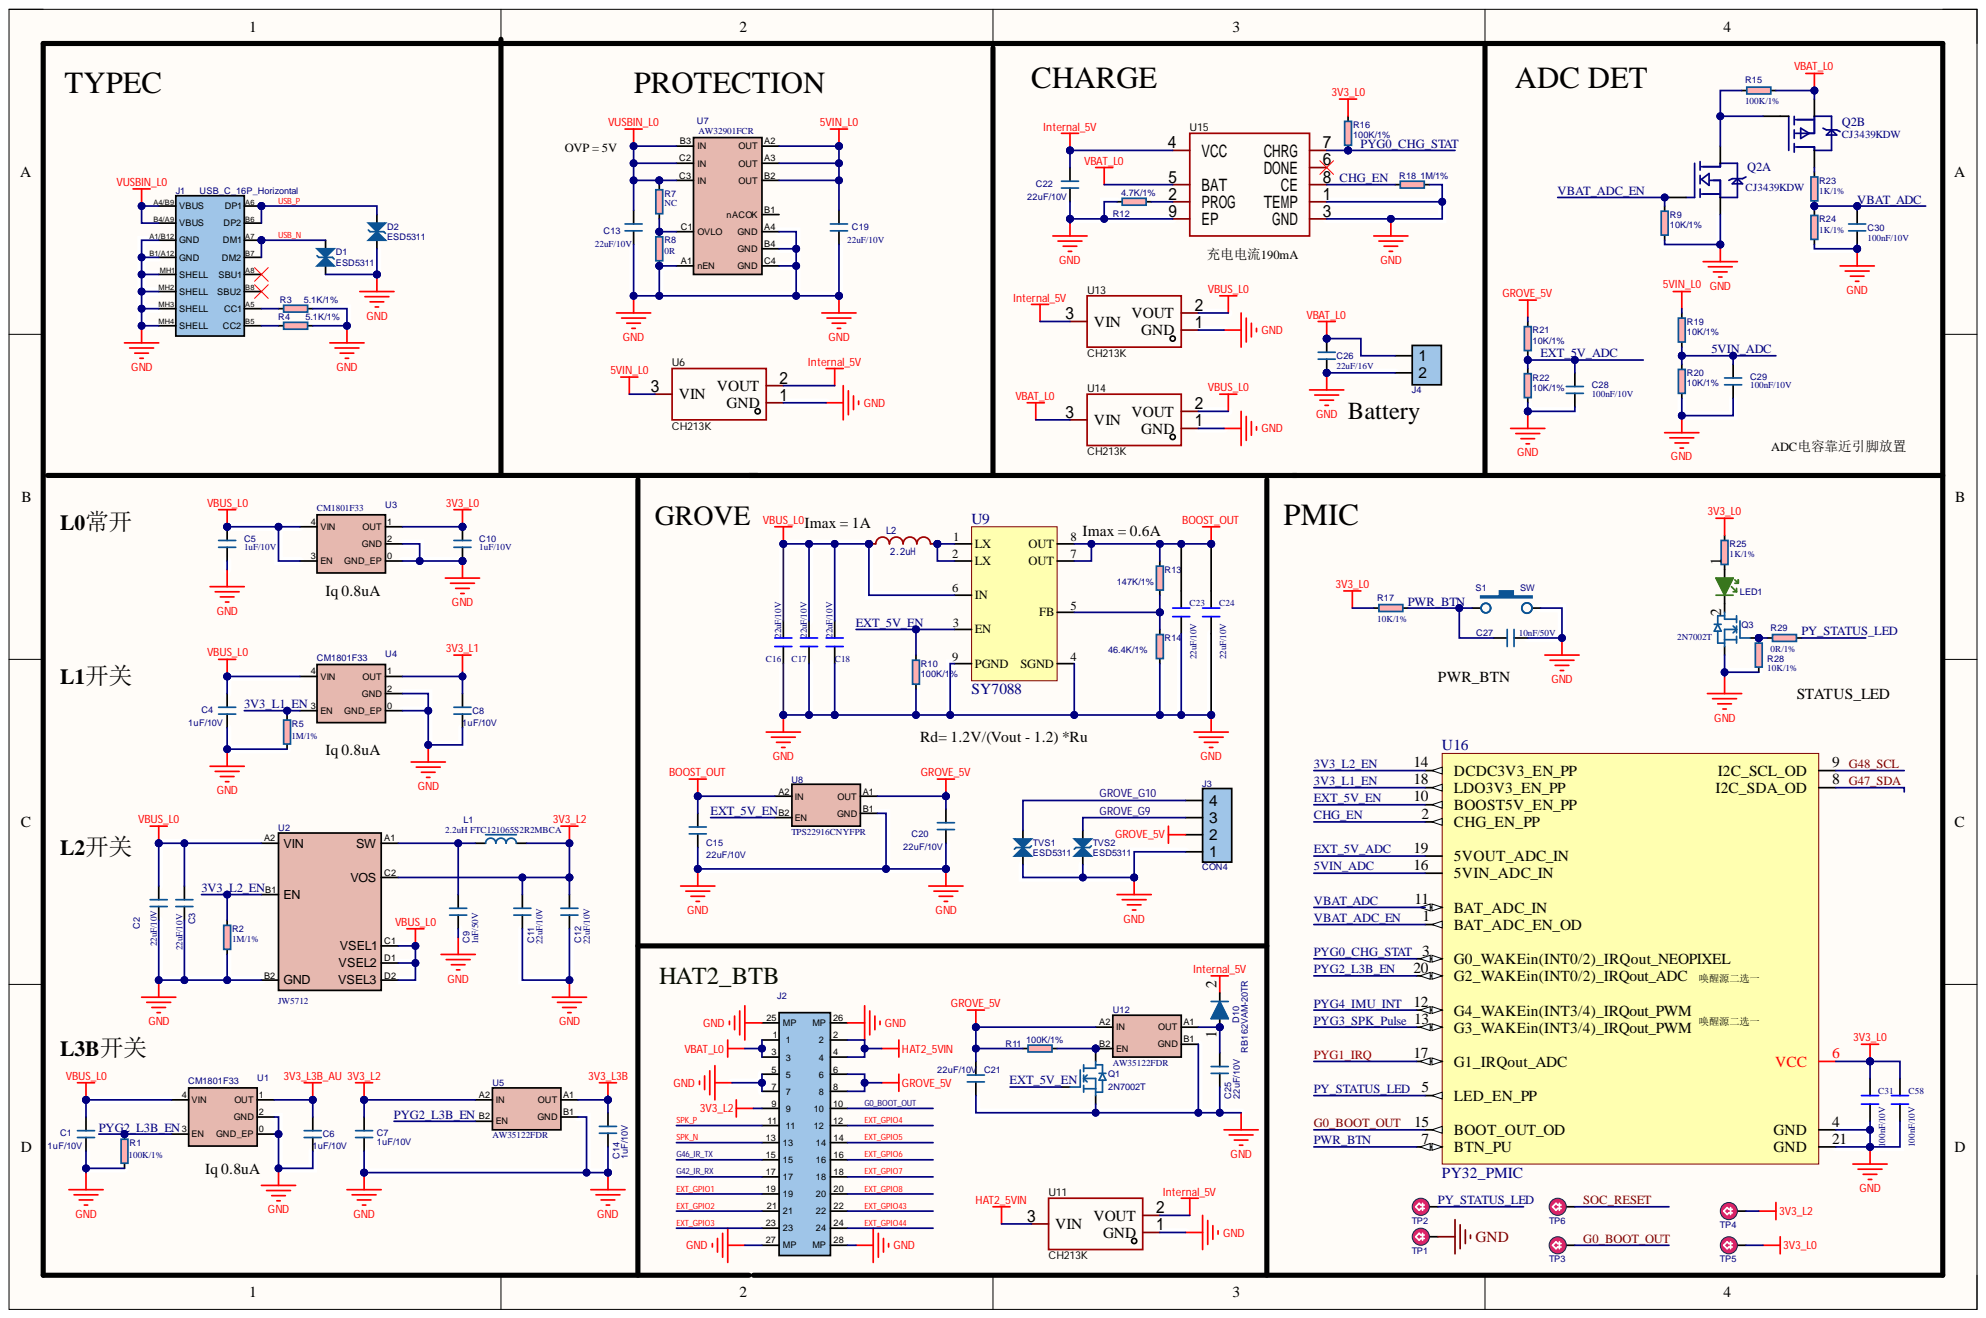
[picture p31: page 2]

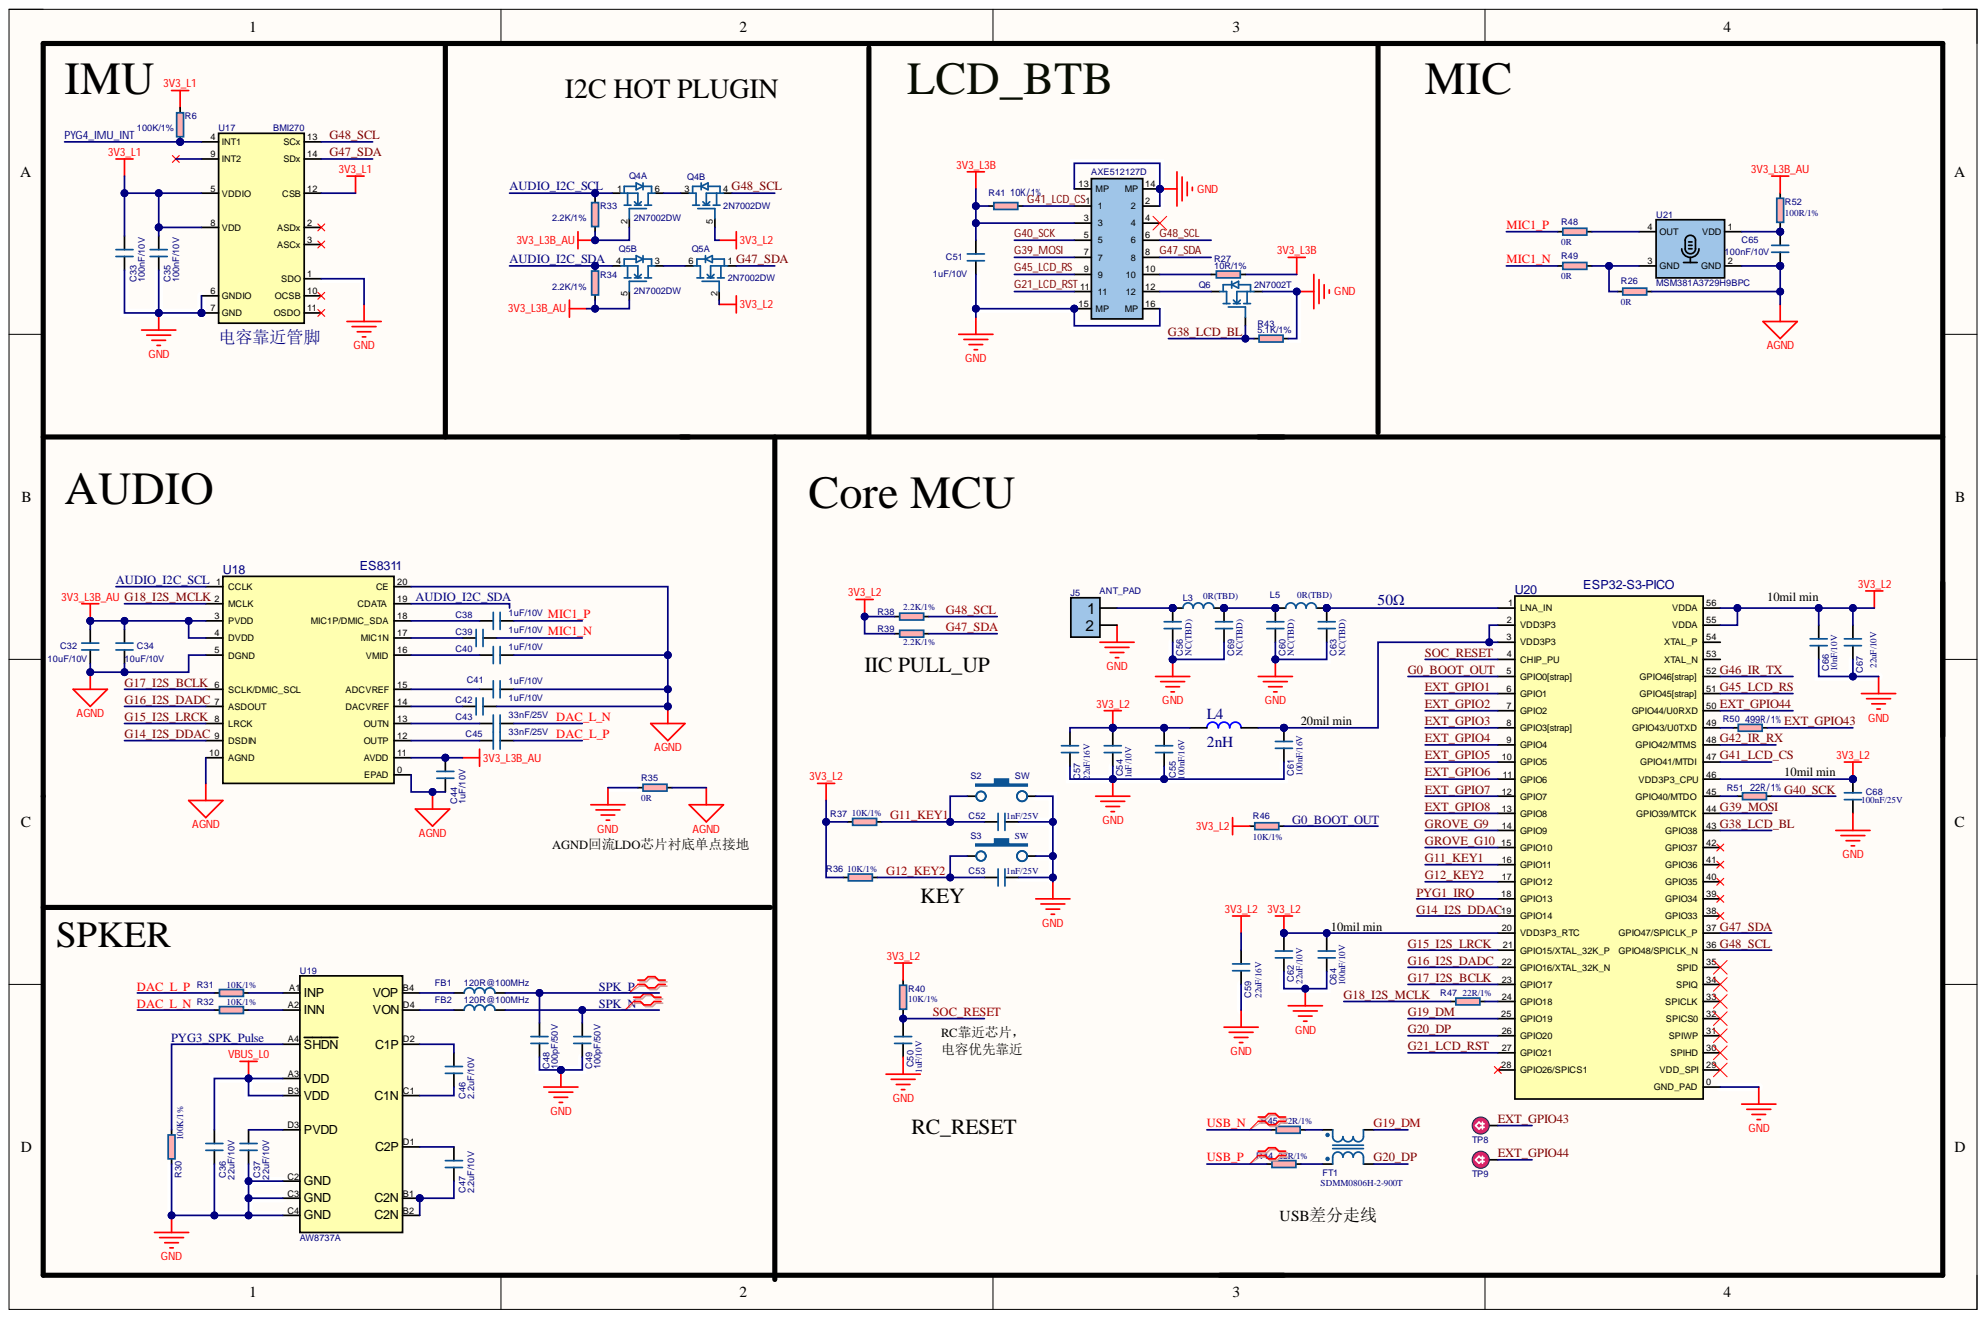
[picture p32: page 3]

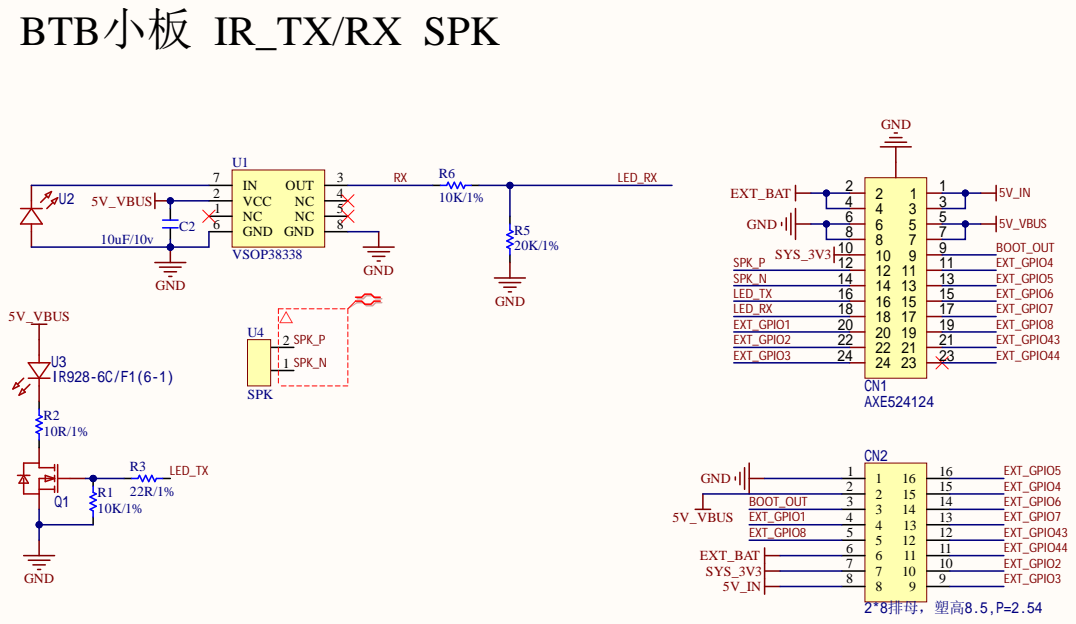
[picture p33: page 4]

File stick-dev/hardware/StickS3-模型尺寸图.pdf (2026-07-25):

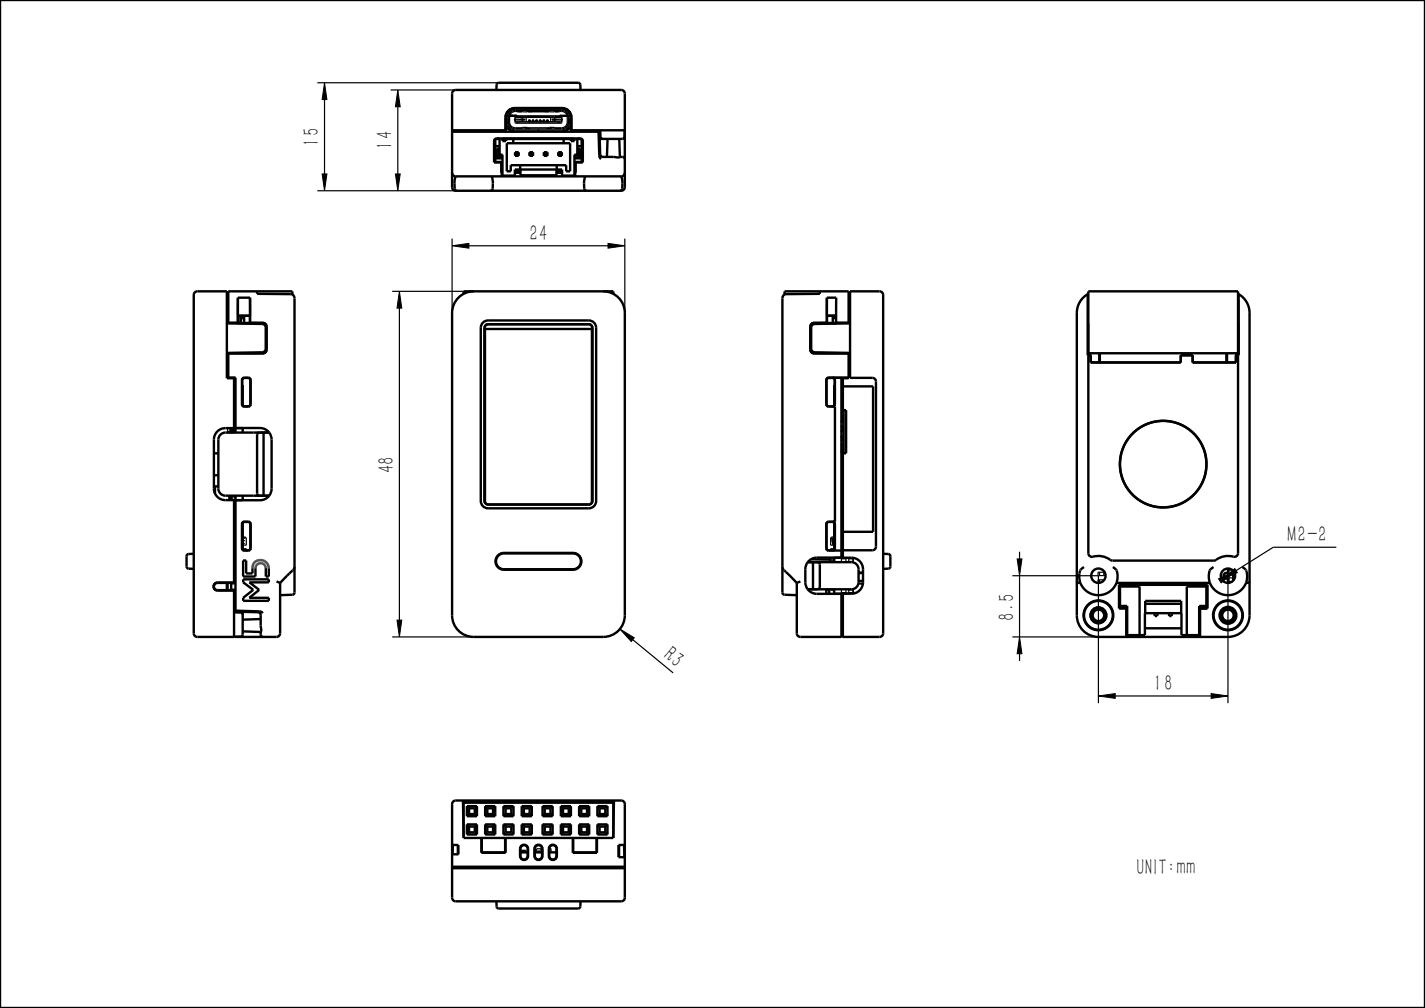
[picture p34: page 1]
UNIT:mm

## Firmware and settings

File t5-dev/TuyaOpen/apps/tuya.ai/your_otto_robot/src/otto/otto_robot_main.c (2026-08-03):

/**
 * @file otto_robot_main.c
 * @brief Otto robot main control module for Tuya IoT projects
 *
 * This file implements the main control logic for the Otto humanoid robot, including movement control,
 * data point processing, cloud communication, and thread management. It provides comprehensive robot
 * control functionality including walking, dancing, gesture recognition, and audio mode management.
 * The module handles various robot actions such as forward/backward movement, turning, swinging,
 * jumping, and complex dance sequences through cloud-based commands and local control interfaces.
 *
 * @copyright Copyright (c) 2021-2025 Tuya Inc. All Rights Reserved.
 *
 */

#include "tuya_cloud_types.h"
#include "tuya_kconfig.h"
#include "tal_api.h"
#include "tkl_output.h"
#include "tkl_pwm.h"
#include "oscillator.h"
#include "otto_movements.h"
#include "otto_motion_ctrl.h"
#include "otto_robot_dp_profile.h"
#include "app_chat_bot.h"
#include "tuya_iot_dp.h"
#include "tuya_iot.h"
#include <string.h>
#include <stdint.h>
#include <stdbool.h>



/***********************************************************
*************************micro define***********************
***********************************************************/

// Forward declarations
void otto_robot_dp_proc_thread(uint32_t move_type);
void otto_init_all_trims(void);
void otto_set_trims_from_kv(void);
#if !defined(OTTO_NO_SERVO_TRIM) || (OTTO_NO_SERVO_TRIM != 1)
void otto_trim_calibration_dp_proc(dp_obj_t *dp);
#endif

// Otto motion speed definitions
#define SPEED_SLOW       1500
#define SPEED_NORMAL     1200
#define SPEED_FAST       800

// Audio mode definitions (matching app_chat_bot.c)
#define AUDIO_MODE_KEY_PRESS_HOLD_SINGLE    0  // Press and hold button to start a single conversation
#define AUDIO_MODE_KEY_TRIG_VAD_FREE        1  // Press the button once to start or stop the free conversation
#define AUDIO_MODE_ASR_WAKEUP_SINGLE        2  // Say the wake-up word to start a single conversation
#define AUDIO_MODE_ASR_WAKEUP_FREE          3  // Say the wake-up word for free conversation

#if !defined(OTTO_NO_SERVO_TRIM) || (OTTO_NO_SERVO_TRIM != 1)
// KV storage keys for Otto robot calibration
#define OTTO_LEFT_LEG_TRIM_KEY "otto_left_leg_trim"
#define OTTO_RIGHT_LEG_TRIM_KEY "otto_right_leg_trim"
#define OTTO_LEFT_FOOT_TRIM_KEY "otto_left_foot_trim"
#define OTTO_RIGHT_FOOT_TRIM_KEY "otto_right_foot_trim"
#define OTTO_LEFT_HAND_TRIM_KEY "otto_left_hand_trim"
#define OTTO_RIGHT_HAND_TRIM_KEY "otto_right_hand_trim"
#define OTTO_TRIM_INIT_FLAG_KEY "otto_trim_init_flag"
#endif

#define OTTO_GPIO_NUM_18   TUYA_PWM_NUM_0
#define OTTO_GPIO_NUM_24   TUYA_PWM_NUM_1
#define OTTO_GPIO_NUM_32   TUYA_PWM_NUM_2
#define OTTO_GPIO_NUM_34   TUYA_PWM_NUM_3
#define OTTO_GPIO_NUM_36   TUYA_PWM_NUM_4
#define OTTO_GPIO_NUM_9    TUYA_PWM_NUM_7
// Otto robot servo pin definitions based on board type
#ifdef OTTO_BOARD_DEFAULT_TXP
// board default txp Otto robot servo pin define
#define PIN_LEFT_LEG   OTTO_GPIO_NUM_18
#define PIN_RIGHT_LEG  OTTO_GPIO_NUM_24
#define PIN_LEFT_FOOT  OTTO_GPIO_NUM_32
#define PIN_RIGHT_FOOT OTTO_GPIO_NUM_34
#define PIN_LEFT_HAND  OTTO_GPIO_NUM_36
#define PIN_RIGHT_HAND OTTO_GPIO_NUM_9

#elif defined(OTTO_BOARD_DREAM)
// board dream Otto robot servo pin define

#define PIN_LEFT_LEG   OTTO_GPIO_NUM_18
#define PIN_RIGHT_LEG  OTTO_GPIO_NUM_9
#define PIN_LEFT_FOOT  OTTO_GPIO_NUM_34
#define PIN_RIGHT_FOOT OTTO_GPIO_NUM_24
#define PIN_LEFT_HAND  OTTO_GPIO_NUM_32
#define PIN_RIGHT_HAND OTTO_GPIO_NUM_36

#else
#error "Please select a board type in Kconfig"
#endif

#define TASK_PWM_PRIORITY THREAD_PRIO_4
#define TASK_PWM_SIZE     4096

/***********************************************************
***********************typedef define***********************
***********************************************************/

/***********************************************************
***********************variable define**********************
***********************************************************/

// External reference to global Otto robot structure
extern Otto_t g_otto;

// Otto motion steps
static uint32_t OTTO_STEP = 2; // otto steps, default is 2

// Otto speed
static uint32_t OTTO_SPEED = SPEED_NORMAL;

// Thread running flag
static bool is_otto_robot_dp_proc_running = false;

// Thread handle
static THREAD_HANDLE robot_app_thread = NULL;

#define OTTO_SHOW_STEPS           2
#define OTTO_SHOW_GAP_MS          150

/***********************************************************
***********************function define**********************
***********************************************************/

/**
 * @brief Set Otto steps
 * @param steps Number of steps
 */
void set_otto_steps(uint32_t steps)
{ 
    OTTO_STEP = steps;
    PR_DEBUG("set otto steps:%d", OTTO_STEP);
}

/**
 * @brief Get Otto steps
 * @return Current number of steps
 */
uint32_t get_otto_steps(void)
{
    return OTTO_STEP;
}

/**
 * @brief Report Otto steps to cloud
 * @param steps Number of steps
 * @return Operation result
 */
static OPERATE_RET _report_otto_step(uint32_t steps)
{
    PR_DEBUG("report otto step dp to cloud");
    tuya_iot_client_t *client = tuya_iot_client_get();
    dp_obj_t dp_obj = {
        .id = DPID_OTTO_STEP,
        .type = PROP_VALUE,
        .value.dp_value = steps,
    };
    return tuya_iot_dp_obj_report(client, client->activate.devid, &dp_obj, 1, 0);
}

/**
 * @brief Process Otto step DP
 * @param steps Number of steps
 */
void otto_robot_step_dp_proc(uint32_t steps)
{
    _report_otto_step(steps);
    set_otto_steps(steps);
    PR_DEBUG("otto_robot_step_dp_proc:%d", steps);
}

/**
 * @brief Set Otto speed
 * @param speed Speed value
 */
void set_otto_speed(uint32_t speed)
{
    OTTO_SPEED = speed;
    PR_DEBUG("set otto speed:%d", OTTO_SPEED);
}

/**
 * @brief Get Otto speed
 * @return Current speed
 */
uint32_t get_otto_speed(void)
{
    return OTTO_SPEED;
}

/**
 * @brief Report Otto speed to cloud
 * @param speed_type Speed type
 * @return Operation result
 */
static OPERATE_RET _report_otto_speed(uint32_t speed_type)
{
    PR_DEBUG("report otto speed dp to cloud");
    tuya_iot_client_t *client = tuya_iot_client_get();
    dp_obj_t dp_obj = {
        .id = DPID_OTTO_SPEED,
        .type = PROP_ENUM,
        .value.dp_enum = speed_type,
    };
    return tuya_iot_dp_obj_report(client, client->activate.devid, &dp_obj, 1, 0);
}

/**
 * @brief Process Otto speed DP
 * @param speed_type Speed type (0:slow ,1:normal, 2:fast)
 */
void otto_robot_speed_dp_proc(uint32_t speed_type)
{
    _report_otto_speed(speed_type);
    switch (speed_type)
    {
        case 0:
            OTTO_SPEED = SPEED_SLOW;
            break;
        case 1:
            OTTO_SPEED = SPEED_NORMAL;
            break;
        case 2:
            OTTO_SPEED = SPEED_FAST;
            break;
        default:
            break;
    }
    set_otto_speed(OTTO_SPEED);
    PR_DEBUG("otto_robot_speed_dp_proc");
}

/**
 * @brief Report Otto audio mode to cloud
 * @param mode Audio mode
 * @return Operation result
 */
static OPERATE_RET _report_otto_audio_mode(uint32_t mode)
{
    PR_DEBUG("report otto audio mode dp to cloud");
    tuya_iot_client_t *client = tuya_iot_client_get();
    dp_obj_t dp_obj = {
        .id = DPID_OTTO_AUDIO,
        .type = PROP_ENUM,
        .value.dp_enum = mode,
    };
    return tuya_iot_dp_obj_report(client, client->activate.devid, &dp_obj, 1, 0);
}

/**
 * @brief Process Otto audio mode DP
 * @param mode Audio mode (0:Key Press Hold Single, 1:Key Trigger VAD Free, 2:ASR Wakeup Single, 3:ASR Wakeup Free)
 */
void otto_robot_audio_mode_dp_proc(uint32_t mode)
{ 
    _report_otto_audio_mode(mode);
    
    // Switch chat mode based on mode parameter
    switch (mode) {
        case AUDIO_MODE_KEY_PRESS_HOLD_SINGLE:
            PR_DEBUG("Switching to Key Press Hold Single mode");
            // This mode is handled by Kconfig ENABLE_CHAT_MODE_KEY_PRESS_HOLD_SINGEL
            // The mode is set at compile time, so we just log the request
            break;
            
        case AUDIO_MODE_KEY_TRIG_VAD_FREE:
            PR_DEBUG("Switching to Key Trigger VAD Free mode");
            // This mode is handled by Kconfig ENABLE_CHAT_MODE_KEY_TRIG_VAD_FREE
            // The mode is set at compile time, so we just log the request
            break;
            
        case AUDIO_MODE_ASR_WAKEUP_SINGLE:
            PR_DEBUG("Switching to ASR Wakeup Single mode");
            // This mode is handled by Kconfig ENABLE_CHAT_MODE_ASR_WAKEUP_SINGEL
            // The mode is set at compile time, so we just log the request
            break;
            
        case AUDIO_MODE_ASR_WAKEUP_FREE:
            PR_DEBUG("Switching to ASR Wakeup Free mode");
            // This mode is handled by Kconfig ENABLE_CHAT_MODE_ASR_WAKEUP_FREE
            // The mode is set at compile time, so we just log the request
            break;
            
        default:
            PR_DEBUG("Unknown audio mode: %d", mode);
            break;
    }
    
    PR_DEBUG("otto_robot_audio_mode_dp_proc completed for mode:%d", mode);
}

bool is_otto_power_on = false;

/**
 * @brief Initialize hand servos only, without affecting leg servos
 */
void otto_init_hands_only_wrapper()
{
    PR_DEBUG("Initializing hands only...");
    
    // Call otto_init_hands_only function from otto_movements.c
    otto_init_hands_only(PIN_LEFT_HAND, PIN_RIGHT_HAND);
    
    PR_DEBUG("Hands initialized successfully.");
}

void otto_power_on()
{
    if (is_otto_power_on) {
        PR_DEBUG("Otto already power on");
        return;
    }
    is_otto_power_on = true;
    PR_DEBUG("Otto initializing...");

#if !defined(OTTO_NO_SERVO_TRIM) || (OTTO_NO_SERVO_TRIM != 1)
    otto_init_all_trims();
#endif

    PR_DEBUG("Initializing legs and feet...");
    otto_init(PIN_LEFT_LEG, PIN_RIGHT_LEG, PIN_LEFT_FOOT, PIN_RIGHT_FOOT, -1, -1);
    otto_enable_servo_limit(SERVO_LIMIT_DEFAULT);
    otto_home(false);
    tal_system_sleep(200);

#if !defined(OTTO_NO_ARMS) || (OTTO_NO_ARMS != 1)
    PR_DEBUG("Initializing hands...");
    otto_init_hands_only_wrapper();
#if !defined(OTTO_NO_SERVO_TRIM) || (OTTO_NO_SERVO_TRIM != 1)
    otto_set_trims_from_kv();
#endif
    otto_home(true);
    PR_DEBUG("Otto initialized completely (with arms).");
#else
    PR_DEBUG("Otto initialized completely (4 servos, no arms).");
#endif
}
/**
 * @brief otto_Show
 *
 * @return none
 */
/**
 * @brief Run one show segment if not aborted
 * @param[in] fn Segment runner (calls one motion primitive)
 * @return true if completed, false if aborted
 */
typedef void (*otto_show_step_fn_t)(void);

static bool __otto_show_step(otto_show_step_fn_t fn)
{
    if (otto_motion_should_abort()) {
        return false;
    }
    fn();
    if (otto_motion_should_abort()) {
        return false;
    }
    otto_motion_sleep_ms(OTTO_SHOW_GAP_MS);
    return !otto_motion_should_abort();
}

static void __show_walk_f(void)
{
    otto_walk(OTTO_SHOW_STEPS, OTTO_SPEED, FORWARD, 20);
}

static void __show_turn_l(void)
{
    otto_turn(OTTO_SHOW_STEPS, OTTO_SPEED, LEFT, 25);
}

static void __show_swing(void)
{
    otto_swing(OTTO_SHOW_STEPS, OTTO_SPEED, 20);
}

static void __show_up_down(void)
{
    otto_up_down(OTTO_SHOW_STEPS, OTTO_SPEED, 20);
}

static void __show_bend(void)
{
    otto_bend(1, OTTO_SPEED, LEFT);
}

static void __show_jitter(void)
{
    otto_jitter(OTTO_SHOW_STEPS, OTTO_SPEED, 20);
}

static void __show_moonwalker(void)
{
    otto_moonwalker(OTTO_SHOW_STEPS, OTTO_SPEED, 20, LEFT);
}

static void __show_jump(void)
{
    otto_jump(1, OTTO_SPEED);
}

#if !defined(OTTO_NO_ARMS) || (OTTO_NO_ARMS != 1)
static void __show_hand_wave(void)
{
    otto_hand_wave(OTTO_SPEED, 0);
}
#endif

/**
 * @brief Compact show sequence; abortable between segments
 * @return none
 */
static void otto_Show(void)
{
    PR_DEBUG("otto_Show start");

    if (!__otto_show_step(__show_walk_f)) {
        return;
    }
    if (!__otto_show_step(__show_turn_l)) {
        return;
    }
    if (!__otto_show_step(__show_swing)) {
        return;
    }
    if (!__otto_show_step(__show_up_down)) {
        return;
    }
    if (!__otto_show_step(__show_bend)) {
        return;
    }
    if (!__otto_show_step(__show_jitter)) {
        return;
    }
    if (!__otto_show_step(__show_moonwalker)) {
        return;
    }
    if (!__otto_show_step(__show_jump)) {
        return;
    }
#if !defined(OTTO_NO_ARMS) || (OTTO_NO_ARMS != 1)
    if (!__otto_show_step(__show_hand_wave)) {
        return;
    }
#endif
    PR_DEBUG("otto_Show complete");
}

enum ActionType {
    ACTION_WALK_F = 0,
    ACTION_WALK_B,
    ACTION_WALK_L,
    ACTION_WALK_R,
    ACTION_NONE,
    ACTION_SWING = 5,
    ACTION_UP_DOWN = 6,
    ACTION_BEND = 7,
    ACTION_JITTER = 8,
    ACTION_MOONWALKER = 9,
    ACTION_JUMP = 10,
    ACTION_SHOW = 11,
    ACTION_HAND_WAVE = 12,
};

/**
 * @brief Thread parameter structure for passing action type
 */
typedef struct {
    uint32_t move_type; ///< Action type, refer to enum ActionType
} OttoMotionThreadParams;

/**
 * @brief Execute a specific Otto robot action
 * 
 * @param move_type The action type to execute
 */
void otto_robot_execute_action(uint32_t move_type)
{
    PR_DEBUG("Executing action: %d", move_type);
    
    switch (move_type) {
    case ACTION_WALK_F:
        PR_DEBUG("Walking forward");
        otto_walk(OTTO_STEP, OTTO_SPEED, FORWARD, 20);
        break;

    case ACTION_WALK_B:
        PR_DEBUG("Walking backward");
        otto_walk(OTTO_STEP, OTTO_SPEED, BACKWARD, 15);
        break;

    case ACTION_WALK_L:
        PR_DEBUG("Walking left");
        otto_turn(OTTO_STEP, OTTO_SPEED, LEFT, 25);
        break;

    case ACTION_WALK_R:
        PR_DEBUG("Walking right");
        otto_turn(OTTO_STEP, OTTO_SPEED, RIGHT, 25);
        break;

    case ACTION_SWING:
        PR_DEBUG("Swinging");
        otto_swing(OTTO_STEP, OTTO_SPEED, 20);
        break;

    case ACTION_UP_DOWN:
        PR_DEBUG("Moving up and down");
        otto_up_down(OTTO_STEP, OTTO_SPEED, 20);
        break;

    case ACTION_BEND:
        PR_DEBUG("Bending");
        otto_bend(OTTO_STEP, OTTO_SPEED, LEFT);
        break;

    case ACTION_JITTER:
        PR_DEBUG("Jittering");
        otto_jitter(OTTO_STEP, OTTO_SPEED, 20);
        break;

    case ACTION_MOONWALKER:
        PR_DEBUG("Performing moonwalker");
        otto_moonwalker(OTTO_STEP, OTTO_SPEED, 20, LEFT);
        break;

    case ACTION_JUMP:
        PR_DEBUG("Jumping");
        otto_jump(OTTO_STEP, OTTO_SPEED);
        break;

    case ACTION_SHOW:
        PR_DEBUG("Performing Show");
        otto_Show();
        break;
        
    case ACTION_HAND_WAVE:
        PR_DEBUG("otto hand wave");
        otto_hand_wave(OTTO_SPEED, 0);
        break;

    case ACTION_NONE:    
        PR_DEBUG("Returning to home position");
        //otto_set_trims(0, 0, 0, 0, 0, 0);
        otto_home(true);
        break;

    default:
        PR_DEBUG("Invalid action type: %d", move_type);
        //otto_set_trims(0, 0, 0, 0, 0, 0);
        otto_home(true);
        break;
    }
    
#if !defined(OTTO_NO_SERVO_TRIM) || (OTTO_NO_SERVO_TRIM != 1)
    otto_set_trims_from_kv();
#endif
#if defined(OTTO_NO_ARMS) && (OTTO_NO_ARMS == 1)
    otto_home(false);
#else
    otto_home(true);
#endif
    PR_DEBUG("Action completed, returned to home position");
}

#if defined(OTTO_PRODUCT_ST7789_V1) && (OTTO_PRODUCT_ST7789_V1 == 1)

/**
 * @brief Map V1 speed enum index to legacy speed type (0:slow, 1:normal, 2:fast)
 * @param[in] speed_enum V1 cloud enum index
 * @return Legacy speed type for otto_robot_speed_dp_proc
 */
static uint32_t __otto_v1_speed_enum_to_legacy(uint32_t speed_enum)
{
    switch (speed_enum) {
    case 0:
        return 1;
    case 1:
        return 0;
    case 2:
        return 2;
    default:
        return 1;
    }
}

/**
 * @brief Map V1 speed enum string to legacy speed type
 * @param[in] speed_str V1 cloud enum string
 * @return Legacy speed type for otto_robot_speed_dp_proc
 */
static uint32_t __otto_v1_speed_str_to_legacy(const char *speed_str)
{
    if (speed_str == NULL) {
        return 1;
    }
    if (strcmp(speed_str, "SPEED_SLOW") == 0) {
        return 0;
    }
    if (strcmp(speed_str, "SPEED_FAST") == 0) {
        return 2;
    }
    return 1;
}

/**
 * @brief Map V1 ptz_control string to internal action type
 * @param[in] ptz_str Cloud enum string
 * @param[out] action_out Internal ActionType value
 * @return true if mapped, false if unknown
 */
static bool __otto_v1_ptz_str_to_action(const char *ptz_str, uint32_t *action_out)
{
    if (ptz_str == NULL || action_out == NULL) {
        return false;
    }
    if (strcmp(ptz_str, "front") == 0) {
        *action_out = ACTION_WALK_F;
    } else if (strcmp(ptz_str, "back") == 0) {
        *action_out = ACTION_WALK_B;
    } else if (strcmp(ptz_str, "left") == 0) {
        *action_out = ACTION_WALK_L;
    } else if (strcmp(ptz_str, "right") == 0) {
        *action_out = ACTION_WALK_R;
    } else if (strcmp(ptz_str, "none") == 0) {
        *action_out = ACTION_NONE;
    } else if (strcmp(ptz_str, "swing") == 0) {
        *action_out = ACTION_SWING;
    } else if (strcmp(ptz_str, "up_down") == 0) {
        *action_out = ACTION_UP_DOWN;
    } else if (strcmp(ptz_str, "bend") == 0) {
        *action_out = ACTION_BEND;
    } else if (strcmp(ptz_str, "jitter") == 0) {
        *action_out = ACTION_JITTER;
    } else if (strcmp(ptz_str, "moonwalker") == 0) {
        *action_out = ACTION_MOONWALKER;
    } else if (strcmp(ptz_str, "jump") == 0) {
        *action_out = ACTION_JUMP;
    } else if (strcmp(ptz_str, "show") == 0) {
        *action_out = ACTION_SHOW;
    } else if (strcmp(ptz_str, "hand") == 0) {
        *action_out = ACTION_HAND_WAVE;
    } else {
        return false;
    }
    return true;
}

/**
 * @brief Process V1 ptz_control DP (DP5)
 * @param[in] dp Data point object
 * @return none
 */
static void __otto_v1_ptz_dp_proc(dp_obj_t *dp)
{
    uint32_t action = ACTION_NONE;

    if (dp->type == PROP_ENUM) {
        action = dp->value.dp_enum;
        if (action > ACTION_HAND_WAVE) {
            PR_DEBUG("Unknown ptz_control enum: %d", action);
            return;
        }
        PR_DEBUG("ptz_control enum index: %d", action);
        otto_robot_dp_proc_thread(action);
        return;
    }
    if (dp->type == PROP_STR) {
        if (!__otto_v1_ptz_str_to_action(dp->value.dp_str, &action)) {
            PR_DEBUG("Unknown ptz_control string: %s", dp->value.dp_str);
            return;
        }
        PR_DEBUG("ptz_control string: %s -> action %d", dp->value.dp_str, action);
        otto_robot_dp_proc_thread(action);
        return;
    }
    PR_DEBUG("Unsupported ptz_control DP type: %d", dp->type);
}

/**
 * @brief Process data points for ST7789 V1 product profile
 * @param[in] dpobj Received DP object bundle
 * @return none
 */
static void __otto_robot_dp_proc_v1(dp_obj_recv_t *dpobj)
{
    for (uint32_t i = 0; i < dpobj->dpscnt; i++) {
        dp_obj_t *dp = dpobj->dps + i;
        PR_DEBUG("V1 DP[%d]: id=%d type=%d", i, dp->id, dp->type);
        switch (dp->id) {
        case DPID_OTTO_PTZ_CONTROL:
            __otto_v1_ptz_dp_proc(dp);
            break;
        case DPID_OTTO_SPEED:
            if (dp->type == PROP_ENUM) {
                otto_robot_speed_dp_proc(__otto_v1_speed_enum_to_legacy(dp->value.dp_enum));
            } else if (dp->type == PROP_STR) {
                otto_robot_speed_dp_proc(__otto_v1_speed_str_to_legacy(dp->value.dp_str));
            }
            break;
        case DPID_OTTO_STEP:
            if (dp->type == PROP_VALUE) {
                uint32_t steps = dp->value.dp_value;
                if (steps < OTTO_STEP_MIN) {
                    steps = OTTO_STEP_MIN;
                }
                if (steps > OTTO_STEP_MAX) {
                    steps = OTTO_STEP_MAX;
                }
                otto_robot_step_dp_proc(steps);
            }
            break;
        case DPID_OTTO_AUDIO:
            if (dp->type == PROP_ENUM) {
                otto_robot_audio_mode_dp_proc(dp->value.dp_enum);
            } else if (dp->type == PROP_STR) {
                if (strcmp(dp->value.dp_str, "hold") == 0) {
                    otto_robot_audio_mode_dp_proc(0);
                } else if (strcmp(dp->value.dp_str, "key") == 0) {
                    otto_robot_audio_mode_dp_proc(1);
                } else if (strcmp(dp->value.dp_str, "weakup") == 0) {
                    otto_robot_audio_mode_dp_proc(2);
                } else if (strcmp(dp->value.dp_str, "free") == 0) {
                    otto_robot_audio_mode_dp_proc(3);
                } else {
                    PR_DEBUG("Unknown audio mode string: %s", dp->value.dp_str);
                }
            }
            break;
        default:
            PR_DEBUG("Unknown V1 DP ID: %d", dp->id);
            break;
        }
    }
}

#endif /* OTTO_PRODUCT_ST7789_V1 */

/**
 * @brief Process data point objects for Otto robot control
 * 
 * @param dpobj Pointer to the data point object structure
 */
void otto_robot_dp_proc(dp_obj_recv_t *dpobj)
{
    PR_DEBUG("=== Otto Robot DP Processing Started ===");
    
    if (dpobj == NULL || dpobj->dpscnt == 0) {
        PR_DEBUG("Invalid dpobj or no dps to process");
        return;
    }
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

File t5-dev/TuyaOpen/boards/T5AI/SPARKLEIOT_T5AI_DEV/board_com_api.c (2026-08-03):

/**
 * @file board_com_api.c
 * @author Tuya Inc.
 * @brief Implementation of common board-level hardware registration APIs for audio, button, and LED peripherals.
 *
 * @copyright Copyright (c) 2021-2025 Tuya Inc. All Rights Reserved.
 */

#include "tuya_cloud_types.h"
#include "tal_api.h"

#include "tkl_gpio.h"
#include "tkl_pinmux.h"

#include "tdd_audio.h"
#include "tdd_button_gpio.h"
#include "tdl_button_manage.h"
#include "tdd_disp_st7789.h"
#include "tdd_tp_cst816x.h"
#include "tdd_camera_ov2640.h"
#include "tdd_camera_gc2145.h"

/* Platform SDIO helpers (implemented in tuyaos_adapter) */
extern OPERATE_RET tkl_sdio_init(int port, const TUYA_SDIO_BASE_CFG_T *cfg);
extern void user_sdio_gpio_init(void);
/***********************************************************
************************macro define************************
***********************************************************/
#define BOARD_SPEAKER_EN_PIN         TUYA_GPIO_NUM_7

#define BOARD_BUTTON_PIN             TUYA_GPIO_NUM_8
#define BOARD_BUTTON_ACTIVE_LV       TUYA_GPIO_LEVEL_LOW

#define BOARD_LCD_BL_TYPE            TUYA_DISP_BL_TP_GPIO 
#define BOARD_LCD_BL_PIN             TUYA_GPIO_NUM_9
#define BOARD_LCD_BL_ACTIVE_LV       TUYA_GPIO_LEVEL_HIGH

#define BOARD_LCD_WIDTH              240
#define BOARD_LCD_HEIGHT             320
#define BOARD_LCD_PIXELS_FMT         TUYA_PIXEL_FMT_RGB565
#define BOARD_LCD_ROTATION           TUYA_DISPLAY_ROTATION_90

#define BOARD_LCD_SPI_PORT           TUYA_SPI_NUM_0
#define BOARD_LCD_SPI_CLK            48000000
#define BOARD_LCD_SPI_CS_PIN         TUYA_GPIO_NUM_45
#define BOARD_LCD_SPI_DC_PIN         TUYA_GPIO_NUM_47
#define BOARD_LCD_SPI_RST_PIN        TUYA_GPIO_NUM_6
#define BOARD_LCD_SPI_MISO_PIN       TUYA_GPIO_NUM_46
#define BOARD_LCD_SPI_CLK_PIN        TUYA_GPIO_NUM_44

#define BOARD_LCD_PIXELS_FMT         TUYA_PIXEL_FMT_RGB565

#define BOARD_LCD_POWER_PIN          TUYA_GPIO_NUM_MAX
#define BOARD_LCD_POWER_ACTIVE_LV    TUYA_GPIO_LEVEL_HIGH

#define BOARD_TP_I2C_PORT            TUYA_I2C_NUM_1
#define BOARD_TP_I2C_SCL_PIN         TUYA_GPIO_NUM_20
#define BOARD_TP_I2C_SDA_PIN         TUYA_GPIO_NUM_21
#define BOARD_TP_RST_PIN             TUYA_GPIO_NUM_23
#define BOARD_TP_INTR_PIN            TUYA_GPIO_NUM_MAX

#define BOARD_CAMERA_I2C_PORT        TUYA_I2C_NUM_0
#define BOARD_CAMERA_I2C_SCL         TUYA_GPIO_NUM_0
#define BOARD_CAMERA_I2C_SDA         TUYA_GPIO_NUM_1

#define BOARD_CAMERA_RST_PIN         TUYA_GPIO_NUM_MAX
#define BOARD_CAMERA_RST_ACTIVE_LV   TUYA_GPIO_LEVEL_LOW

#define BOARD_CAMERA_POWER_PIN       TUYA_GPIO_NUM_MAX
#define BOARD_CAMERA_PWR_ACTIVE_LV   TUYA_GPIO_LEVEL_LOW

#define BOARD_CAMERA_CLK             24000000

/* SDIO MODE1: GPIO14~GPIO19 */
#define BOARD_SDIO_CLK_PIN           TUYA_GPIO_NUM_14
#define BOARD_SDIO_CMD_PIN           TUYA_GPIO_NUM_15
#define BOARD_SDIO_D0_PIN            TUYA_GPIO_NUM_16
#define BOARD_SDIO_D1_PIN            TUYA_GPIO_NUM_17
#define BOARD_SDIO_D2_PIN            TUYA_GPIO_NUM_18
#define BOARD_SDIO_D3_PIN            TUYA_GPIO_NUM_19

/***********************************************************
***********************variable define**********************
***********************************************************/

/***********************************************************
***********************function define**********************
***********************************************************/
OPERATE_RET __board_register_audio(void)
{
    OPERATE_RET rt = OPRT_OK;

#if defined(AUDIO_CODEC_NAME)
    TDD_AUDIO_T5AI_T cfg = {0};
    memset(&cfg, 0, sizeof(TDD_AUDIO_T5AI_T));

#if defined(ENABLE_AUDIO_AEC) && (ENABLE_AUDIO_AEC == 1)
    cfg.aec_enable = 1;
#else
    cfg.aec_enable = 0;
#endif

    cfg.ai_chn      = TKL_AI_0;
    cfg.sample_rate = TKL_AUDIO_SAMPLE_16K;
    cfg.data_bits   = TKL_AUDIO_DATABITS_16;
    cfg.channel     = TKL_AUDIO_CHANNEL_MONO;

    cfg.spk_sample_rate  = TKL_AUDIO_SAMPLE_16K;
    cfg.spk_pin          = BOARD_SPEAKER_EN_PIN;
    cfg.spk_pin_polarity = TUYA_GPIO_LEVEL_LOW;

    TUYA_CALL_ERR_RETURN(tdd_audio_register(AUDIO_CODEC_NAME, cfg));
#endif
    return rt;
}

static OPERATE_RET __board_register_button(void)
{
    OPERATE_RET rt = OPRT_OK;

#if defined(BUTTON_NAME)
    BUTTON_GPIO_CFG_T button_hw_cfg = {
        .pin   = BOARD_BUTTON_PIN,
        .level = BOARD_BUTTON_ACTIVE_LV,
        .mode  = BUTTON_IRQ_MODE,
        .pin_type.irq_edge = TUYA_GPIO_IRQ_FALL,
    };

    TUYA_CALL_ERR_RETURN(tdd_gpio_button_register(BUTTON_NAME, &button_hw_cfg));
#endif

    return rt;
}


static OPERATE_RET __board_register_display(void)
{
    OPERATE_RET rt = OPRT_OK;
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

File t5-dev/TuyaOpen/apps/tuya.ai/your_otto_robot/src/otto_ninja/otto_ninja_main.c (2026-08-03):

/**
 * @file otto_ninja_main.c
 * @brief OttoNinja Robot Main Control Module
 *
 * This file implements the main control logic for the OttoNinja robot, including:
 * - Joystick input processing (X-axis, Y-axis)
 * - Button input processing (A, B, X, Y buttons)
 * - Motion mode switching (walk mode/roll mode)
 * - Data point (DP) message processing
 * - Robot control task creation and management
 *
 * Main functions:
 * 1. Receive and process control commands from the cloud (joystick, buttons, mode switching)
 * 2. Convert control commands to robot motion control function calls
 * 3. Create independent task to run robot main control loop
 * 4. Manage motion mode state (walk mode/roll mode)
 *
 * @note This module depends on otto_ninja_app_servo module for actual servo control
 * @note Supports enabling/disabling arm and head servo functions via ARM_HEAD_ENABLE macro
 *
 * @copyright Copyright (c) 2021-2025 Tuya Inc. All Rights Reserved.
 *
 */


#include "tkl_pwm.h"
#include "tal_sw_timer.h"

// Include servo control header files
#include "otto_ninja_app_servo.h"
#include "otto_ninja_main.h"

 
 /***********************************************************
 *************************micro define***********************
 ***********************************************************/

 #define TASK_OTTO_NINJA_PRIORITY THREAD_PRIO_2
 #define TASK_OTTO_NINJA_SIZE     4096
 
 /***********************************************************
 ***********************typedef define***********************
 ***********************************************************/

 
 /***********************************************************
 ***********************variable define**********************
 ***********************************************************/
 static THREAD_HANDLE sg_otto_ninja_handle;
 static TIMER_ID sg_direction_timer = NULL;
 
 /***********************************************************
 ***********************function define**********************
 ***********************************************************/
static void __direction_timer_cb(TIMER_ID timer_id, void *arg)
{
    (void)timer_id;
    (void)arg;

    PR_DEBUG("Direction timer callback triggered after 3 seconds");
    sg_direction_timer = NULL;
    set_joystick_y(0);
    set_joystick_x(0);
}

// These values are assumed to be obtained from remote control or sensors
/**
 * @brief Set joystick X-axis value
 * @param value: Joystick X-axis value
 * @return none
 */
int8_t joystick_x = 0;
void set_joystick_x(int8_t value){
    joystick_x = value;
}
/**
  * @brief Get joystick X-axis value
  * @return Joystick X-axis value
  */
int8_t get_joystick_x(void){
    return joystick_x;
}
/**
  * @brief Set joystick Y-axis value
  * @param value: Joystick Y-axis value
  * @return none
  */
int8_t joystick_y = 0;
void set_joystick_y(int8_t value){
    joystick_y = value;
}
/**
  * @brief Get joystick Y-axis value
  * @return Joystick Y-axis value
  */
int8_t get_joystick_y(void){
    return joystick_y;
}



bool sport_mode_change = false;
/**
  * @brief Set sport mode change flag
  * @param value: Sport mode change flag value (true means mode switch is needed)
  * @return none
  */
void set_sport_mode_change(bool value){
    sport_mode_change = value;
}
/**
  * @brief Get sport mode change flag
  * @return Sport mode change flag value
  */
bool get_sport_mode_change(void){
    return sport_mode_change;
}


static int mode_counter = 0;  // 0=walk mode, 1=roll mode
void set_mode_counter(int value){
    mode_counter = value;
}
int get_mode_counter(void){
    return mode_counter;
}

#define DPID_JOYSTIC 101
#define SPORT_MODE 102 // roll or walk mode

#define DPID_JOYSTICK_X 103 //joystick_x
#define DPID_JOYSTICK_Y 104 //joystick_y
#define DPID_DIRECTION 105 //direction
#define DPID_ROTATE_SPOT 106 //rotate_spot
OPERATE_RET otto_ninja_dp_obj_proc(dp_obj_recv_t *dpobj)
{
    uint32_t index = 0;
    for (index = 0; index < dpobj->dpscnt; index++) {
        dp_obj_t *dp = dpobj->dps + index;
        PR_DEBUG("idx:%d dpid:%d type:%d ts:%u", index, dp->id, dp->type, dp->time_stamp);

        switch (dp->id) {

        case SPORT_MODE:{

            set_sport_mode_change(true);//Trigger mode switch

            if(dp->value.dp_bool){

                set_mode_counter(1);
                PR_DEBUG("robot_set_roll");
            }else{

                set_mode_counter(0);
                PR_DEBUG("robot_set_walk");
            }
            
            break;
        }

        case DPID_ROTATE_SPOT: {
            if (dp->value.dp_bool) {
                robot_rotate_spot(true);
            } else {
                robot_rotate_spot_stop();
                set_joystick_y(0);
                set_joystick_x(0);
            }
            break;
        }




        case DPID_JOYSTICK_X:{
            int8_t joystick_x = dp->value.dp_value;
            set_joystick_x(joystick_x);
            PR_DEBUG("joystick_x:%d", joystick_x);
            break;
        }

        case DPID_JOYSTICK_Y:{
            int8_t joystick_y = dp->value.dp_value;
            set_joystick_y(joystick_y);
            PR_DEBUG("joystick_y:%d", joystick_y);
            break;
        }

        case DPID_DIRECTION:{
            int8_t direction = dp->value.dp_enum;
            if(direction == 0){
                set_joystick_y(100);
                set_joystick_x(0);
            }
            else if(direction == 1){
                set_joystick_y(-100);
                set_joystick_x(0);
            }
            else if(direction == 2){
                set_joystick_y(100);
                set_joystick_x(100);
            }
            else if(direction == 3){
                set_joystick_y(100);
                set_joystick_x(-100);
            }
            else if(direction == 4){
                set_joystick_y(0);
                set_joystick_x(0);
            }

            PR_DEBUG("direction:%d", direction);
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

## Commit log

2026-07-24 Initial commit: MoneyGod multi-agent quant research engine
    A2A Remote Agent for the PandaAI Next AI Trader track: Planner/Factor/
    Strategy/Backtest/Risk/Report multi-agent workflow with a real feedback
    loop (Backtest results drive Strategy re-generation), self-computed
    deterministic backtest/metrics/risk engine, panda_data market data
    adapter, and a compliance guardrail enforcing risk disclaimers on every
    output.
2026-07-24 Add PandaAI submission doc: architecture, Skills usage, 3 verified example tasks
    Example task outputs are real HTTP responses captured from the live
    public deployment (http://47.98.99.199:8000), not fabricated — includes
    full multi-agent trace, factor scores, backtest numbers, and confirms
    the compliance disclaimer is present in every response.
2026-07-24 Add M4 advisor layer: 签文 (fortune slip) as the first thing users see
    Previously the workflow result jumped straight into the multi-agent
    trace/backtest tables — never delivering on the product's core "抽签"
    concept. src/advisor.py deterministically derives an action verdict
    (buy/hold/reduce/watch) from the real backtest sharpe/drawdown and risk
    level (no LLM), maps it to a pre-written ceremonial signature phrase,
    and a plain-language one-liner. Wired into both the A2A text response
    (leads the render) and the Web UI (fortune card now renders first,
    reusing CSS that existed but was previously unused dead code).
2026-07-24 Add design spec for Injective on-chain notary (签文存证)
    Extends MoneyGod to the Injective AI x Blockchain track: anchor a
    sha256 hash of each workflow's advice+report+disclaimer as a memo on
    a Injective testnet MsgSend, so AI-generated advice becomes tamper-
    evident. Also gitignores local ainj dev-tooling config (.claude/,
    .ainj/) that setup wrote into the project root.
2026-07-24 Add implementation plan for Injective on-chain notary feature
    9 tasks: generate testnet wallet, claim faucet funds, implement
    notary.py (TDD for pure hash functions, integration-verified for the
    real chain broadcast), wire Advisor+Notary into research_workflow(),
    render on-chain status in both A2A text and Web UI, update Agent Card,
    deploy to production and verify end-to-end publicly.
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2026-07-24 Add Injective testnet faucet claim/poll script
    Wallet inj1zhr2f2m0uv2gvh6t38s8jgz9hs5q4svyvmyngg funded with 1 INJ
    via manual web faucet after the automated API endpoint returned 404.
    Confirmed on-chain via fetch_bank_balance.
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2026-07-24 Render on-chain attestation status in A2A text output; dedupe advisor call
    Removes the now-redundant advisor.to_advice() calls from tasks.py
    (research_workflow() sets result["advice"] itself since Task 5). Adds
    _render_onchain() alongside _render_fortune() so the on-chain status
    line appears right after the 签文 in the A2A text response.
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2026-07-24 Fix notary.py: close gRPC channel, empty timeout reason, dead import, hash-in-try
    Fixes from final whole-branch code review on the production-live notary.anchor()
    path (called on every multi-agent workflow run):
    - Close the AsyncClient's chain gRPC channel (and its background timeout-height
    sync task) in a finally block after each broadcast, so channels don't
    accumulate for the lifetime of the long-running server process.
    - Fall back to the exception's class name when asyncio.TimeoutError's str() is
    empty, so the A2A/Web UI "本次未能上链...()" message isn't left with empty
    parens.
    - Drop the unused `import time`.
    - Move canonical-payload/hash/memo construction inside anchor()'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
2026-07-24 Add Injective track submission doc with real, independently-verified example
    Architecture, tooling (official pyinjective SDK + ainj agent skills),
    and one example task's on-chain attestation triple-verified: local hash
    recompute matches API response's onchain.hash, which matches the memo
    queried directly from Injective testnet's LCD REST API (code:0,
    indexed). Team info and the reflective questionnaire fields (difficulties
    encountered, feedback on Injective docs) are left as placeholders for
    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
2026-07-25 perf(fortune): 关闭 Seed 模型思考链, 求签延时 30s->6s
    根因: SEED 端点默认开深度思考, 单次 reasoning_tokens 高达 1190,
    签文属创意任务无需思考链。llm.ask/ask_json 增加 thinking 开关,
    fortune 传 thinking=disabled, LLM 预算 8s->12s。实测端到端 5-6s,
    落入板端 HTTP 10s / 思考动画 12s 预算内。
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2026-07-25 feat(stick): single lottery GIF for idle+shake, 3x replay, audio self-test diagnostics
    - idle shows static frame 0 of getting_lottery.gif, thinking.gif removed
    - shake plays the animation SHAKE_ANIM_REPEATS(3) times before returning to idle
    - GIF draw callback honors transparency index (fixes black delta frames)
    - boot self-test screen: speaker state, ES8311/PM1 I2C presence, PA enable bit
    - track project assets (qianpu_v2.json, scene GIFs, T5 hardware docs, fontbuild)
    - ignore upstream TuyaOpen clones and debug scratch files
    [config.h, main.cpp]
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2026-07-25 Fix PandaAI A2A submission blockers: protocol version, silent workflow failure, response timeout
    - card.py: bump declared protocolVersion 0.2.6 -> 0.3.0. The organizers'
    self-check tool rejects any card not matching /^0.3/, failing card
    validation before it ever attempts a real call. Wire format is unaffected
    (checker treats both as the same legacy 0.x schema).
    - serve.py: force PROTOCOL_BUFFERS_PYTHON_IMPLEMENTATION=python before any
    other import. pyinjective vendors its own google/api/http.proto that
    collides with the copy googleapis-common-protos (an a2a-sdk dependency)
    registers; the default C++/upb protobuf backend throws on the duplicate
    registration. That exception was b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
2026-07-25 feat(web): 把像素动画素材接进网页端
    scene_change_gifs/ 里的素材原来只喂 t5-dev 的固件流水线，网页端还是纯 emoji。
    现在同一批素材也用到 Web UI 上，硬件端和网页端视觉统一。
    - tools/prep_web_gifs.py: 新增网页版压制脚本。源素材里 opening_1(1536x1024)
    和 getting_lottery(1016x677) 对网页太大，统一等比缩到 480 宽以内 + 调色板量化，
    9 个 GIF 从 3.3MB 压到 814KB。产物提交进仓库，换素材时才需要重跑。
    - app.py: /gifs 挂 StaticFiles 静态目录（目录不存在时跳过挂载，不影响服务起来）。
    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
2026-08-03 refactor: 砍掉 A2A/PandaAI、区块链、量化引擎、网站与 iMessage 桥
    项目范围收敛到「板子 + 后端接口」两块,后端只保留赛博财神庙求签服务。
    删除:
    - A2A/PandaAI:executor.py、card.py、a2a-sdk 依赖、两条 .well-known 路由、
    config.MAX_RESPONSE_SECONDS、PandaAI 开发备忘与赛道提交文档
    - 区块链:notary.py、injective-py 依赖、test_notary.py、三个 Injective 脚本、
    Injective 提交说明与 superpowers 下的 notary 设计/计划文档
    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
2026-08-03 chore: 解除 t5-dev/TuyaOpen/ 的忽略规则,改为只忽略构建产物
    固件源码即将由 git subtree 纳入本仓库,原先那条'外部 clone,单独提交'
    的忽略规则会让 subtree 引入的文件处于被忽略状态,必须先解除。
    Claude-Session: https://claude.ai/code/session_01DRz9QQq98WP4fiJQtEh6C6
2026-08-03 Squashed 't5-dev/TuyaOpen/' content from commit 48c75995
    git-subtree-dir: t5-dev/TuyaOpen
    git-subtree-split: 48c75995f6a12f03252cfb111938347edcf593b6
    [display.csv, flash.cfg, hx1230_commands.ods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]
2026-08-03 chore: 合并固件仓库进主仓,修复子模块与构建脚本
    把 moneyGod-TuyaOpen 以 git subtree 纳入 t5-dev/TuyaOpen/,两个仓库合并为一个。
    用 --squash 只导入当前快照:完整历史约 200MB,全量导入会让每个人每次 clone
    都付这个代价;历史仍保留在 moneyGod-TuyaOpen 仓库,并作为 upstream 同步点。
    配套修复(都是"vendor 进子目录"直接导致的,不修则 clone 下来编不了):
    1. 四个原 git submodule(FlashDB / littlefs / cJSON / backoffAlgorithm)改为
    普通文件签入。git 只认仓库根的 .gitmodules,作为 subtree 它们会退化成
    解析不了的死 gitlink。现在 clone 即可编译,无需 git submodule updat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
    [partitions.csv]
2026-08-03 fix(cyber_fortune): 补 USB 打印驱动桩,恢复固件可编译
    干净 checkout 下 tos.py build 会在最终链接失败:
    fortune_printer.c:257: undefined reference to `bk_usbh_printer_is_connected'
    fortune_printer.c:264: undefined reference to `bk_usbh_printer_write'
    排查结论(与合仓无关,是既有问题):
    - 这两个符号在 platform/T5AI 全树里都不存在 —— 源码里没有,所有预编译 .a
    用 nm 扫过也没有
    - CherryUSB 确实带 class/printer/usbh_printer.c,但它没被列进
    components/bk_usb/CMakeLists.txt(压根不参与编译),且不含 bk_usbh_printer_ 包装
    - 能工作的实现只存在于某位开发者本地的 platform/T5AI 里,而该目录被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
2026-08-03 feat(hardware): 加入外壳 3D 模型(最终确定版)
    13 个 binary STL + 一个打包好的 zip,放在顶层 hardware/3d-models/,
    方便只想打印外壳的人直接下载,不必 clone 整个带 TuyaOpen SDK 的仓库。
    - STL 与来源文件逐字节一致,剔除 __MACOSX/ 与 .DS_Store
    - moneygod-shrine-stl.zip 由这 13 个 STL 重新打包,供一键下载
    - README 含零件清单(包围盒尺寸/面数,解析 STL 得出)、下载链接、打印建议
    - .gitattributes 将 *.stl 标为 binary linguist-generated
    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
    [02_roof_liner.stl, 0301.stl, 0302.stl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]
2026-08-03 chore(hardware): 移除打包 zip,改用稀疏检出获取模型
    zip 与同目录 STL 完全重复,没必要在库里存两份。
    README 改为「网页单个下载 + git sparse-checkout 拉整个目录」,
    后者同样能避开体积很大的 TuyaOpen SDK。
    Claude-Session: https://claude.ai/code/session_01WMCQX8r4Ae3ZQe1XpiW5v2
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2026-08-04 chore(hardware): update 0303.stl (庙身主体) with revised model
    [0303.stl]
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
